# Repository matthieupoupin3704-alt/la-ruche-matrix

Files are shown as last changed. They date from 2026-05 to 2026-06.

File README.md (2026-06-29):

# La Ruche Matrix

**Wi-Fi controlled LED matrix panel for live events: ESP32-S3 + 1 024 WS2812B LEDs on a motorized 2-axis structure.**

Built by Matthieu POUPIN & Marceau GUIGUI - Option Culture Maker, Eirlab / ENSEIRB-MATMECA, 2026.

<p align="center">
  La Ruche Matrix in action
</p>

---

## Overview

La Ruche Matrix is an interactive LED panel designed for music events. The audience connects from their phone and can display scrolling text, draw pixel by pixel, or pick from 31 animations: all in real time, without any app.

- **1 024 RGB LEDs:** 4 × WS2812B 16×16 panels chained together
- **Wi-Fi control:** connect to the panel like a hotspot, open a browser, done
- **31 animations:** Matrix rain, Pac-Man, Game of Life, Pong, 3D cube, audio visualizer...
- **2-axis motorized structure:** repositions the panel without dismounting anything
- **Budget: ~150–160 €**

---

## Demo

<p align="center">
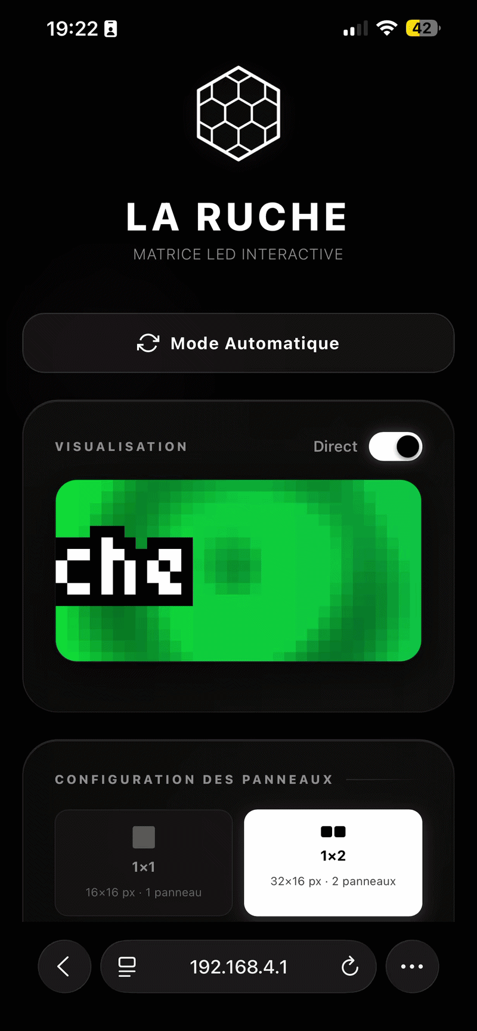
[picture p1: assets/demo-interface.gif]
Web interface demo
  
</p>

---

## Hardware

### Electronics

| Component | Qty | Notes |
|---|-----|---|
| ESP32-S3-N16R8 | 1 | Main controller: Wi-Fi, native USB, 16 MB flash |
| WS2812B 16×16 LED panels | 4 | Individually addressable, chained in series |
| Megatronics v3.3 | 1 | Salvaged, runs Marlin, controls motors via ATmega2560 |
| 19.5 V PSU (modified PC adapter) | 1 | Salvaged |
| XL1509 buck converter | 1 | 19.5 V → 5 V, powers ESP32 |
| BSS138 4-channel level shifter | 1 | 3.3 V ↔ 5 V between ESP32 and Megatronics |
| MAX9814 microphone | 1 | Audio-reactive animations |
| Wires, connectors, perfboard | | |

<p align="center">
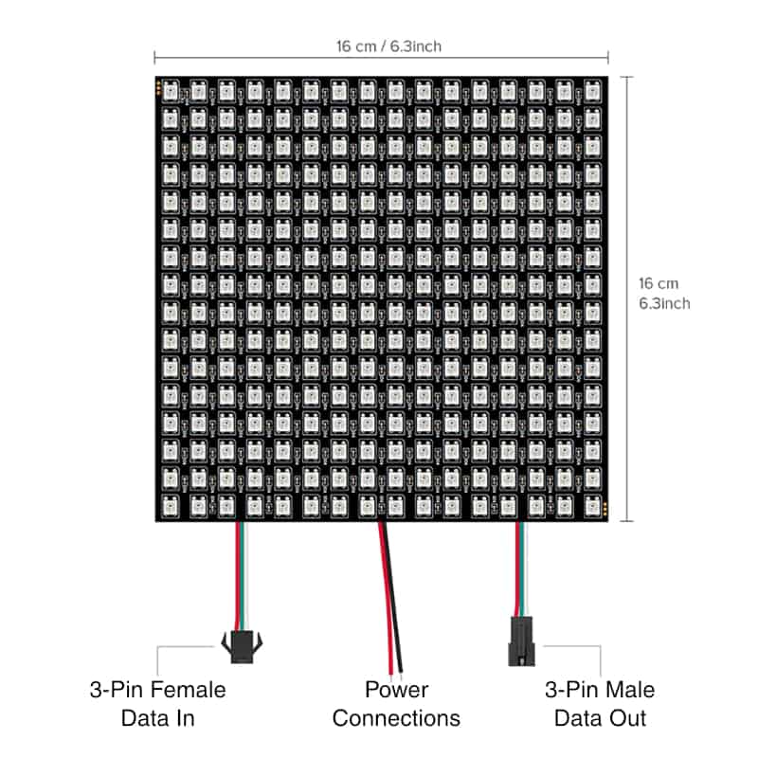
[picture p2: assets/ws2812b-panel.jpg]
WS2812B 16×16 panel and connectors
  
  <br><em>WS2812B 16×16 panel: Data In, Power, Data Out</em>
</p>

<p align="center">
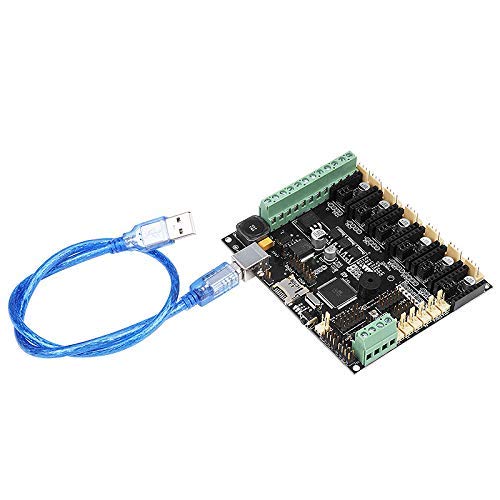
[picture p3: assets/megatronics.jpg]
Megatronics v3.3
  
  <br><em>Megatronics v3.3: runs Marlin, controls the stepper motors</em>
</p>

<p align="center">
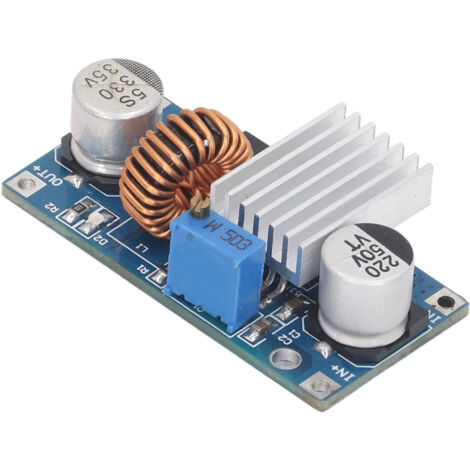
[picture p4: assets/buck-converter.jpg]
XL1509 buck converter
  
  <br><em>XL1509 adjustable buck converter: 19.5 V → 5 V</em>
</p>

### Mechanical

The structure is inspired by a Cartesian 3D printer: two independent axes let you reposition the panel in space without unmounting it from the light bridge.

| Component | Qty | Unit price |
|---|-----|---|
| SH16/SK16 shaft supports | 4 | 6.11 € |
| SH8/SK8 shaft supports | 4 | 4.26 € |
| SC16UU linear bearings (∅16 mm) | 4 | 15.27 € |
| SC8UU linear bearings (∅8 mm) | 2 | 4.95 € |
| ∅16 mm h6 precision shaft (500 mm) | 2 | 9.64 € |
| ∅8 mm h6 precision shaft (500 mm) | 2 | 5.91 € |
| TR10×4P2 trapezoidal leadscrew (500 mm) | 2 | 5.85 € |
| TR10×4P2 bronze/alu leadscrew nut | 2 | 31.63 € |
| D20L25 flexible coupling (5/10 mm) | 2 | 6.60 € |
| GT2 open belt 6 mm (~1 000 mm) | 4 | 7.15 € |
| GT2 20-tooth pulley (5 mm bore) | 2 | 2.27 € |
| NEMA 17 stepper motors (42SH0034D) | 2 | Salvaged (~10 € each otherwise) |
| PLA printed parts | | STL files in this repo |
| Aluminium profiles + hardware | | Frame reinforcement |

**Y axis (vertical):** a NEMA 17 drives a TR10×4P2 trapezoidal leadscrew. A second screw synchronized by belt ensures parallel motion. The bronze nut integral to the carriage moves up or down as the screw turns: slow, precise, and self-locking (no power needed to hold position).

**X axis (horizontal):** the second motor drives a carriage along 16 mm precision shafts via GT2 belt.

<p align="center">
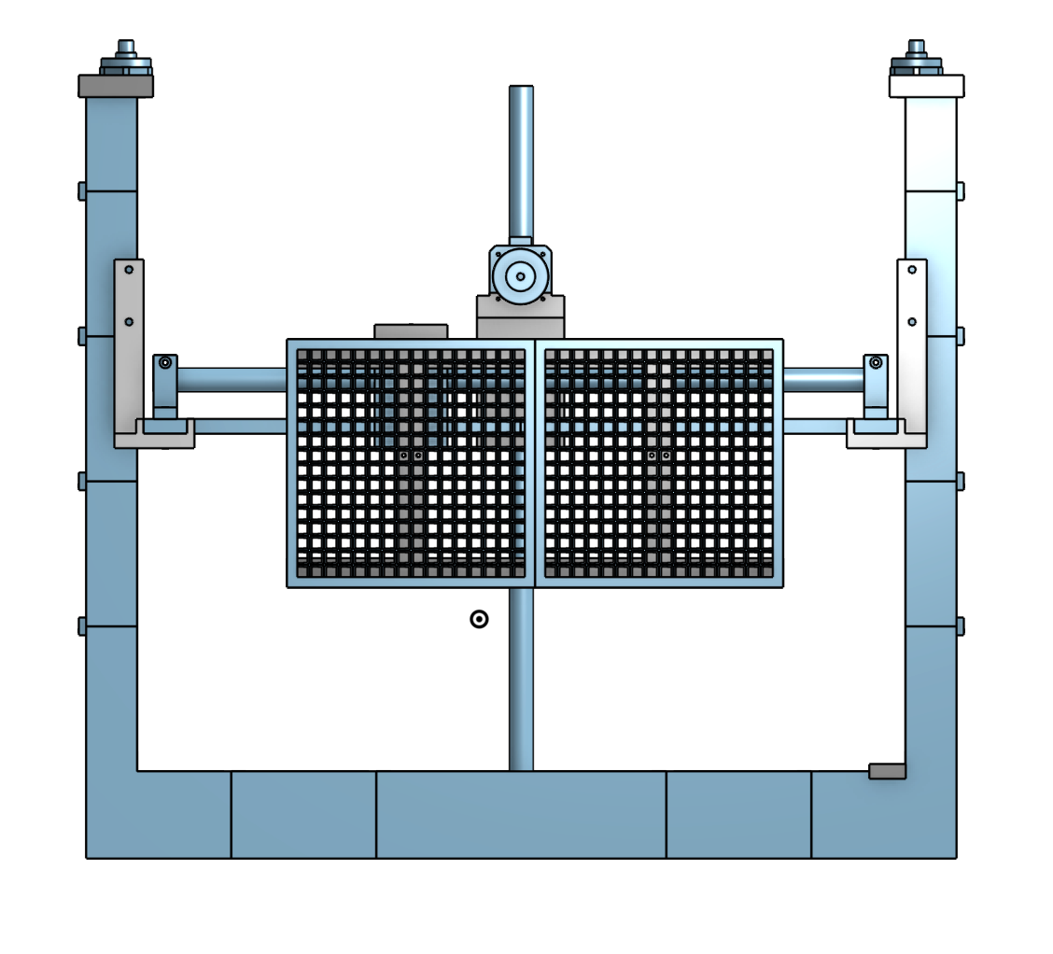
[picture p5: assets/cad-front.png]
CAD front view
  
  <br><em>Front view: 3D CAD of the mechanical structure</em>
</p>

<p align="center">
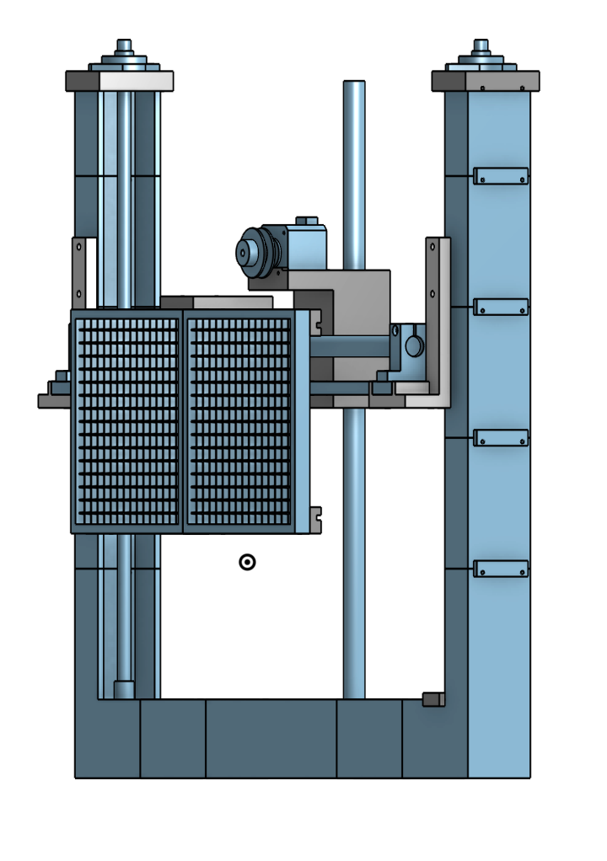
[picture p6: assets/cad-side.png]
CAD side view
  
  <br><em>Side view</em>
</p>

### Tools required

- 3D printer (PLA)
- Soldering iron
- Multimeter
- VSCode + PlatformIO extension

---

## Wiring

19.5 V feeds the XL1509 buck converter, which steps down to 5 V. This 5 V goes into the ESP32-S3's `5V IN` pin; the ESP regulates internally to 3.3 V. The four WS2812B panels are powered from this 3.3 V rail. They tolerate it in practice, and FastLED caps total current at 500 mA. The motors are powered directly at 19.5 V through the Megatronics.

The four panels are chained in series: a single data wire from **GPIO 5** runs through each panel in order. **A common ground between the ESP, panels, and Megatronics is mandatory**. Without it, the data signal is interpreted randomly.

<p align="center">
  Wiring diagram
  <br><em>Simplified wiring diagram</em>
</p>

The ESP32-S3 runs at 3.3 V and the ATmega2560 at 5 V. A BSS138 4-channel level shifter is required between the two.

<p align="center">
  Level shifter wiring
</p>

---

## Firmware

### Quickstart (5 minutes)

1. Install [VSCode](https://code.visualstudio.com/) + the **PlatformIO** extension
2. Clone the repo: `git clone https://github.com/matthieupoupin3704-alt/la-ruche-matrix`
3. Open the folder in VSCode
4. Plug in the ESP32-S3 via USB-C (N16R8 recommended for RAM)
5. In PlatformIO: click **Upload** (`esp32dev` environment)

PlatformIO downloads dependencies, compiles, and flashes automatically.

### Code structure

| File | Role |
|---|---|
| `src/main.cpp` | Web server, scrolling text, settings persistence, dual-core task management |
| `include/effects.h` | 31 animations, each effect is an independent function |

### Dual-core architecture

The ESP32 has two cores: Wi-Fi handles HTTP requests on core 0, while LEDs compute and render on core 1. A mutex protects shared buffers (without it, random visual corruption occurs).

<p align="center">
  Dual-core diagram
  <br><em>Dual-core task architecture</em>
</p>

### Image pipeline

<p align="center">
  Image pipeline
  <br><em>Effect → Topology mapping → Physical output</em>
</p>

### Topologies

Switchable at runtime from the web interface, no recompilation needed. Resolution (`matW`, `matH`) and active LED count are global variables recalculated on the fly. Choice is persisted in ESP flash.

| Topology | Resolution | Panels |
|---|---|---|
| 1×1 | 16×16 px | 1 |
| 1×2 | 32×16 px | 2 side by side |
| 1×4 | 64×16 px | 4 in a strip |
| 2×2 | 32×32 px | 4 in a square |

### Motor control

The Megatronics v3.3 runs Marlin on its ATmega2560. The ESP32 sends G-code over UART (Serial3, 115200 baud). Marlin handles acceleration and motion profiles natively.

```cpp
// Relative mode: no need to track absolute position
snprintf(buf, sizeof(buf), "G91\nG1 Z%.1f X%.1f F%d\nG90", dz, dx, feedrate);
Serial1.println(buf);
```

Emergency stop sends `M410` immediately.

In `marlin_config/Configuration.h`:

```cpp
#define SERIAL_PORT 0      // ATmega native USB
#define SERIAL_PORT_2 3    // Serial3 → ESP32
#define BAUDRATE_2 115200
```

> **Note:** The vertical motor is wired to the Z slot on the Megatronics, not Y. The Y driver was faulty on this salvaged board.

---

## Usage

### Connecting

1. Power on the panel
2. On your phone: Wi-Fi → connect to **La-Ruche-Matrix**
3. Open a browser and go to `192.168.4.1`

The interface works on any mobile browser.

### What you can do

- **Scrolling text:** type a message, pick one of 7 fonts (from tiny pixel art to large sans-serif), send. Text color adapts to the chosen hue.
- **Freehand drawing:** touchscreen canvas for pixel-by-pixel drawing, with pencil, eraser, and a La Ruche logo button.
- **31 animations:** Matrix rain, Doom corridor, Pac-Man, Game of Life, Pong, rotating 3D cube, audio visualizer, and more. Each reacts to hue, speed, and brightness. Some react to sound via the MAX9814 microphone.
- **Panel movement:** touchscreen D-pad sends movement commands, with an emergency stop button.
- **Auto mode:** the panel cycles through animations and fonts every 15 seconds automatically.
- **Live preview:** toggle a real-time view of what's displayed on the panel in your browser, useful for technicians standing behind it.

---

## Adding your own animations

In `include/effects.h`, all animations follow the same pattern:

```cpp
void myEffect() {
    for (uint8_t y = 0; y < MATRIX_H; y++)
        for (uint8_t x = 0; x < MATRIX_W; x++)
            _px(x, y) = CHSV(COULEUR_HUE + x * 4, 255, 200);
}
```

- `_px(x, y)` writes a pixel in logical coordinates
- `COULEUR_HUE` is the hue chosen by the user
- `MATRIX_W` / `MATRIX_H` adapt automatically to the active topology

Then add the function to `_table[]`, its name to `_names[]`, and increment `COUNT`: the interface picks it up automatically.

---

## Known limitations

- **Y axis:** mechanical roughness on one of the vertical shafts now blocks movement
- **X axis:** GT2 belt was particularly difficult to set up (a leadscrew would have been a better choice here)

---

## Acknowledgements

Thanks to [Eirlab](https://www.eirlab.net/) for providing the workspace, equipment loans, and material purchases that made this project possible.

Special thanks to **Julien Allali**, **Antonio Berejano**, and **Adrien Boussicault** for their guidance and support throughout the project.

---

## License

Open source. Code and CAD files available in this repository.

---

*Matthieu POUPIN & Marceau GUIGUI - ENSEIRB-MATMECA, Eirlab, 2026*  
*Full build log: [eirlab.net](https://www.eirlab.net/2026/04/20/lumiere-scenique/)*

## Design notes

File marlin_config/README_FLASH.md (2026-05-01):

# Flasher Marlin sur la Megatronics v3.3

## Prérequis

- Arduino IDE 2.x **ou** PlatformIO
- Câble USB-B (le gros carré, comme pour une imprimante)
- Jumper RESET-EN en place sur la Megatronics (sinon le flash ne fonctionne pas)

## Étapes

### 1. Télécharger Marlin

```bash
git clone https://github.com/MarlinFirmware/Marlin.git
cd Marlin
git checkout release-2.1.2.2
```

### 2. Copier les fichiers de config

Copier `Configuration.h` et `Configuration_adv.h` de ce dossier dans `Marlin/Marlin/`.

```bash
cp /chemin/vers/marlin_config/Configuration.h Marlin/Marlin/
cp /chemin/vers/marlin_config/Configuration_adv.h Marlin/Marlin/
```

### 3. Flash via Arduino IDE

1. Ouvrir `Marlin/Marlin.ino` dans Arduino IDE
2. **Tools → Board** : `Arduino Mega or Mega 2560`
3. **Tools → Processor** : `ATmega2560`
4. **Tools → Port** : le port série de la Megatronics (ex. `/dev/cu.usbserial-XXXX`)
5. Cliquer **Upload**

### 4. Flash via PlatformIO

```bash
cd Marlin
# Vérifier que platformio.ini cible mega2560
pio run -e mega2560 --target upload
```

## Configuration appliquée

| Paramètre | Valeur | Raison |
|---|---|---|
| `SERIAL_PORT` | 3 | Serial3 = connecteur NXT (D14/D15) → ESP32 |
| `BAUDRATE` | 115200 | Vitesse UART ESP32 ↔ ATmega |
| `EXTRUDERS` | 0 | Pas d'extrudeur |
| `TEMP_SENSOR_0` | 0 | Pas de thermisteur |
| `TEMP_SENSOR_BED` | 0 | Pas de plateau chauffant |
| `X_BED_SIZE` | 350 | Course X en mm |
| `Y_BED_SIZE` | 440 | Course Y en mm |
| `DEFAULT_AXIS_STEPS_PER_UNIT` | X=5, Y=50 | GT2+20dents→5pas/mm ; TR10x4P2→50pas/mm |
| Endstops | désactivés | Pas d'endstops sur la structure |

## Câblage ESP32 ↔ Megatronics

La communication passe par le connecteur **NXT** de la Megatronics :

```
Megatronics NXT         Pont logique 3.3V↔5V       ESP32-S3
─────────────────       ─────────────────────       ────────
1. 5V ──────────────── HV (alimentation pont)
2. GND ─────────────── GND ──────────────────────── GND
3. D14 (TX3) ────────── HV1 → LV1 ─────────────────── GPIO44 (RX)
4. D15 (RX3) ────────── LV2 → HV2 ◄──────────────── GPIO43 (TX)
                        LV (3.3V) ◄──── 3.3V ESP32
```

**Important** : ne pas connecter directement 5V ATmega → 3.3V ESP32 sans pont logique.

## Test rapide

Une fois flashé, connecter via le port USB de la Megatronics et envoyer depuis le moniteur série :

```
G28 X Y    ; homing (sans endstops = juste reset position à 0)
G1 X175 Y220 F3000  ; aller au centre
M114       ; afficher la position courante
```

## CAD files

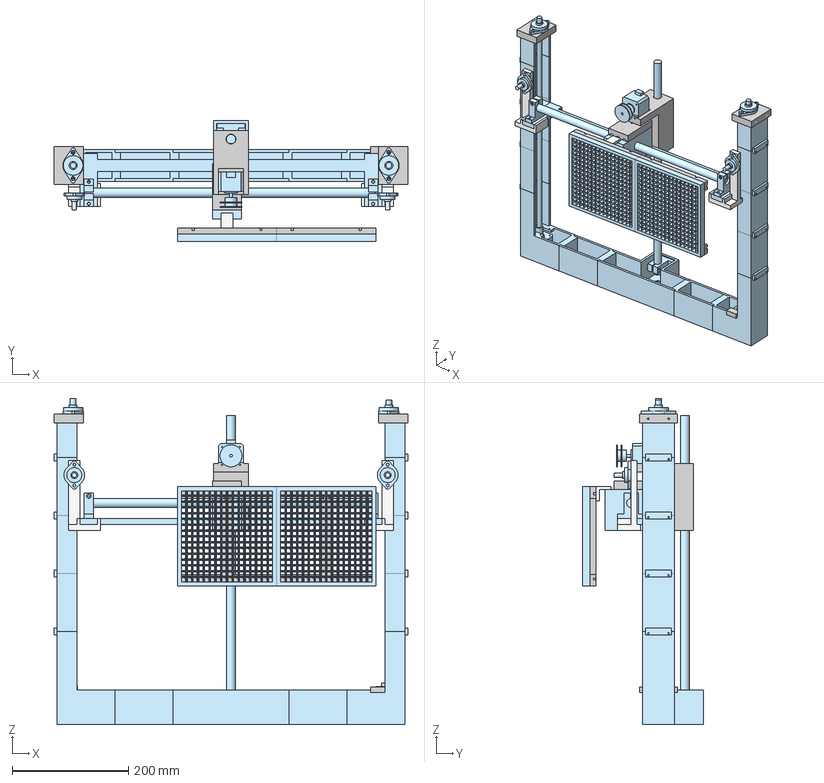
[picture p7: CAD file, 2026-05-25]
Assembly finale.step
610.0 x 208.5 x 562.0 mm

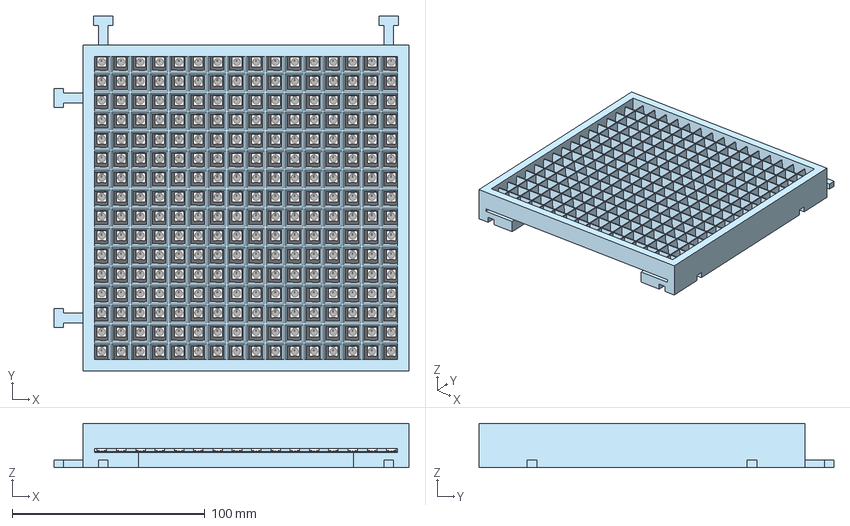
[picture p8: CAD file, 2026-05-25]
Panneau.step
184.0 x 184.0 x 23.0 mm
WS2812_RGB_LED_updated v1 x 256
ws2812b_matrix_16x16 v4

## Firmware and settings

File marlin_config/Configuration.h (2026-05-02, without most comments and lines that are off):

#pragma once
#define CONFIG_EXAMPLES_DIR "config/examples/RepRapWorld/Megatronics"
#define CONFIGURATION_H_VERSION 02010202
#define STRING_CONFIG_H_AUTHOR "La Ruche Matrix" // Who made the changes.
#define SHOW_BOOTSCREEN
  #define MOTHERBOARD BOARD_MEGATRONICS_3
#define SERIAL_PORT 3
#define BAUDRATE 115200
#define X_DRIVER_TYPE  A4988
#define Y_DRIVER_TYPE  A4988
#define Z_DRIVER_TYPE  A4988
#define E0_DRIVER_TYPE A4988
#define EXTRUDERS 0
#define DEFAULT_NOMINAL_FILAMENT_DIA 1.75
#define PSU_CONTROL
  #define PSU_ACTIVE_STATE LOW      // Set 'LOW' for ATX, 'HIGH' for X-Box
#define TEMP_SENSOR_0 0
#define TEMP_SENSOR_1 0
#define TEMP_SENSOR_2 0
#define TEMP_SENSOR_3 0
#define TEMP_SENSOR_4 0
#define TEMP_SENSOR_5 0
#define TEMP_SENSOR_6 0
#define TEMP_SENSOR_7 0
#define TEMP_SENSOR_BED 0
#define TEMP_SENSOR_PROBE 0
#define TEMP_SENSOR_CHAMBER 0
#define TEMP_SENSOR_COOLER 0
#define TEMP_SENSOR_BOARD 0
#define TEMP_SENSOR_REDUNDANT 0
#define DUMMY_THERMISTOR_998_VALUE  25
#define DUMMY_THERMISTOR_999_VALUE 100
#if TEMP_SENSOR_IS_MAX_TC(0)
  #define MAX31865_SENSOR_OHMS_0      100 // (Ω) Typically 100 or 1000 (PT100 or PT1000)
  #define MAX31865_CALIBRATION_OHMS_0 430 // (Ω) Typically 430 for Adafruit PT100; 4300 for Adafruit PT1000
#endif
#if TEMP_SENSOR_IS_MAX_TC(1)
  #define MAX31865_SENSOR_OHMS_1      100
  #define MAX31865_CALIBRATION_OHMS_1 430
#endif
#if TEMP_SENSOR_IS_MAX_TC(2)
  #define MAX31865_SENSOR_OHMS_2      100
  #define MAX31865_CALIBRATION_OHMS_2 430
#endif
#if HAS_E_TEMP_SENSOR
  #define TEMP_RESIDENCY_TIME         10  // (seconds) Time to wait for hotend to "settle" in M109
  #define TEMP_WINDOW                  1  // (°C) Temperature proximity for the "temperature reached" timer
  #define TEMP_HYSTERESIS              3  // (°C) Temperature proximity considered "close enough" to the target
#endif
#if TEMP_SENSOR_BED
  #define TEMP_BED_RESIDENCY_TIME      0  // (seconds) Time to wait for bed to "settle" in M190
  #define TEMP_BED_WINDOW              1  // (°C) Temperature proximity for the "temperature reached" timer
  #define TEMP_BED_HYSTERESIS          3  // (°C) Temperature proximity considered "close enough" to the target
#endif
#if TEMP_SENSOR_CHAMBER
  #define TEMP_CHAMBER_RESIDENCY_TIME 10  // (seconds) Time to wait for chamber to "settle" in M191
  #define TEMP_CHAMBER_WINDOW          1  // (°C) Temperature proximity for the "temperature reached" timer
  #define TEMP_CHAMBER_HYSTERESIS      3  // (°C) Temperature proximity considered "close enough" to the target
#endif
#if TEMP_SENSOR_REDUNDANT
  #define TEMP_SENSOR_REDUNDANT_SOURCE    E1  // The sensor that will provide the redundant reading.
  #define TEMP_SENSOR_REDUNDANT_TARGET    E0  // The sensor that we are providing a redundant reading for.
  #define TEMP_SENSOR_REDUNDANT_MAX_DIFF  10  // (°C) Temperature difference that will trigger a print abort.
#endif
#define HEATER_0_MINTEMP   5
#define HEATER_1_MINTEMP   5
#define HEATER_2_MINTEMP   5
#define HEATER_3_MINTEMP   5
#define HEATER_4_MINTEMP   5
#define HEATER_5_MINTEMP   5
#define HEATER_6_MINTEMP   5
#define HEATER_7_MINTEMP   5
#define BED_MINTEMP        5
#define CHAMBER_MINTEMP    5
#define HEATER_0_MAXTEMP 275
#define HEATER_1_MAXTEMP 275
#define HEATER_2_MAXTEMP 275
#define HEATER_3_MAXTEMP 275
#define HEATER_4_MAXTEMP 275
#define HEATER_5_MAXTEMP 275
#define HEATER_6_MAXTEMP 275
#define HEATER_7_MAXTEMP 275
#define BED_MAXTEMP      150
#define CHAMBER_MAXTEMP  60
#define HOTEND_OVERSHOOT 15   // (°C) Forbid temperatures over MAXTEMP - OVERSHOOT
#define BED_OVERSHOOT    10   // (°C) Forbid temperatures over MAXTEMP - OVERSHOOT
#define COOLER_OVERSHOOT  2   // (°C) Forbid temperatures closer than OVERSHOOT
#define PIDTEMP           // See the PID Tuning Guide at https://reprap.org/wiki/PID_Tuning
#define PID_MAX  255      // Limit hotend current while PID is active (see PID_FUNCTIONAL_RANGE below); 255=full current
#define PID_K1     0.95   // Smoothing factor within any PID loop
    #define DEFAULT_Kp  22.20
    #define DEFAULT_Ki   1.08
    #define DEFAULT_Kd 114.00
#define MAX_BED_POWER 255 // limits duty cycle to bed; 255=full current
#define MAX_CHAMBER_POWER 255 // limits duty cycle to chamber heater; 255=full current
  #define PID_FUNCTIONAL_RANGE 10 // If the temperature difference between the target temperature and the actual temperature
#define PREVENT_COLD_EXTRUSION
#define EXTRUDE_MINTEMP 170
#define PREVENT_LENGTHY_EXTRUDE
#define EXTRUDE_MAXLENGTH 200
#define THERMAL_PROTECTION_HOTENDS // Enable thermal protection for all extruders
#define THERMAL_PROTECTION_BED     // Enable thermal protection for the heated bed
#define THERMAL_PROTECTION_CHAMBER // Enable thermal protection for the heated chamber
#define THERMAL_PROTECTION_COOLER  // Enable thermal protection for the laser cooling
#define USE_ZMIN_PLUG
#define ENDSTOPPULLUPS
#define X_MIN_ENDSTOP_INVERTING true  // Set to true to invert the logic of the endstop.
#define Y_MIN_ENDSTOP_INVERTING true  // Set to true to invert the logic of the endstop.
#define Z_MIN_ENDSTOP_INVERTING true  // Set to true to invert the logic of the endstop.
#define I_MIN_ENDSTOP_INVERTING false // Set to true to invert the logic of the endstop.
#define J_MIN_ENDSTOP_INVERTING false // Set to true to invert the logic of the endstop.
#define K_MIN_ENDSTOP_INVERTING false // Set to true to invert the logic of the endstop.
#define U_MIN_ENDSTOP_INVERTING false // Set to true to invert the logic of the endstop.
#define V_MIN_ENDSTOP_INVERTING false // Set to true to invert the logic of the endstop.
#define W_MIN_ENDSTOP_INVERTING false // Set to true to invert the logic of the endstop.
#define X_MAX_ENDSTOP_INVERTING true  // Set to true to invert the logic of the endstop.
#define Y_MAX_ENDSTOP_INVERTING true  // Set to true to invert the logic of the endstop.
#define Z_MAX_ENDSTOP_INVERTING true  // Set to true to invert the logic of the endstop.
#define I_MAX_ENDSTOP_INVERTING false // Set to true to invert the logic of the endstop.
#define J_MAX_ENDSTOP_INVERTING false // Set to true to invert the logic of the endstop.
#define K_MAX_ENDSTOP_INVERTING false // Set to true to invert the logic of the endstop.
#define U_MAX_ENDSTOP_INVERTING false // Set to true to invert the logic of the endstop.
#define V_MAX_ENDSTOP_INVERTING false // Set to true to invert the logic of the endstop.
#define W_MAX_ENDSTOP_INVERTING false // Set to true to invert the logic of the endstop.
#define Z_MIN_PROBE_ENDSTOP_INVERTING true  // Set to true to invert the logic of the probe.
#define DEFAULT_AXIS_STEPS_PER_UNIT   { 80, 800, 400, 0 }  // 1/16 microstepping DRV8825
#define DEFAULT_MAX_FEEDRATE          { 300, 300, 5, 25 }
#define DEFAULT_MAX_ACCELERATION      { 3000, 3000, 100, 10000 }
#define DEFAULT_ACCELERATION          3000    // X, Y, Z and E acceleration for printing moves
#define DEFAULT_RETRACT_ACCELERATION  3000    // E acceleration for retracts
#define DEFAULT_TRAVEL_ACCELERATION   3000    // X, Y, Z acceleration for travel (non printing) moves
#define DEFAULT_EJERK    5.0  // May be used by Linear Advance
  #define JUNCTION_DEVIATION_MM 0.013 // (mm) Distance from real junction edge
  #define JD_HANDLE_SMALL_SEGMENTS    // Use curvature estimation instead of just the junction angle
#define Z_MIN_PROBE_USES_Z_MIN_ENDSTOP_PIN
#define NOZZLE_TO_PROBE_OFFSET { -25, -29, -12.35 }
#define PROBING_MARGIN 10
#define XY_PROBE_FEEDRATE (133*60)
#define Z_PROBE_FEEDRATE_FAST (4*60)
#define Z_PROBE_FEEDRATE_SLOW (Z_PROBE_FEEDRATE_FAST / 2)
#define Z_CLEARANCE_DEPLOY_PROBE   15 // (mm) Z Clearance for Deploy/Stow
#define Z_CLEARANCE_BETWEEN_PROBES  5 // (mm) Z Clearance between probe points
#define Z_CLEARANCE_MULTI_PROBE     5 // (mm) Z Clearance between multiple probes
#define Z_PROBE_LOW_POINT          -2 // (mm) Farthest distance below the trigger-point to go before stopping
#define Z_PROBE_OFFSET_RANGE_MIN -20
#define Z_PROBE_OFFSET_RANGE_MAX 20
#define X_ENABLE_ON 0
#define Y_ENABLE_ON 0
#define Z_ENABLE_ON 0
#define E_ENABLE_ON 0 // For all extruders
#define DISABLE_OTHER_EXTRUDERS   // Keep only the active extruder enabled
#define INVERT_X_DIR false
#define INVERT_Y_DIR true
#define INVERT_Z_DIR false
#define INVERT_E0_DIR false
#define INVERT_E1_DIR false
#define INVERT_E2_DIR false
#define INVERT_E3_DIR false
#define INVERT_E4_DIR false
#define INVERT_E5_DIR false
#define INVERT_E6_DIR false
#define INVERT_E7_DIR false
#define X_HOME_DIR -1
#define Y_HOME_DIR -1
#define Z_HOME_DIR -1
#define X_BED_SIZE 350
#define Y_BED_SIZE 440
#define X_MIN_POS 0
#define Y_MIN_POS 0
#define Z_MIN_POS 0
#define X_MAX_POS X_BED_SIZE
#define Y_MAX_POS Y_BED_SIZE
#define Z_MAX_POS 200
#define MIN_SOFTWARE_ENDSTOPS
  #define MIN_SOFTWARE_ENDSTOP_X
  #define MIN_SOFTWARE_ENDSTOP_Y
  #define MIN_SOFTWARE_ENDSTOP_Z
  #define MIN_SOFTWARE_ENDSTOP_I
  #define MIN_SOFTWARE_ENDSTOP_J
  #define MIN_SOFTWARE_ENDSTOP_K
  #define MIN_SOFTWARE_ENDSTOP_U
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

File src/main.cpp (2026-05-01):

#include <Arduino.h>
#include <WiFi.h>
#include <WebServer.h>
#include <Preferences.h>
#include <esp_log.h>

#include <Adafruit_GFX.h>
#include <Fonts/FreeMono9pt7b.h>
#include <Fonts/FreeMonoBold12pt7b.h>
#include <Fonts/FreeMonoOblique12pt7b.h>
#include <Fonts/FreeSans9pt7b.h>
#include <Fonts/FreeSans12pt7b.h>
#include <Fonts/FreeSansBold12pt7b.h>
#include <Fonts/FreeSansBold18pt7b.h>
#include <Fonts/FreeSansBoldOblique12pt7b.h>
#include <Fonts/FreeSerif12pt7b.h>
#include <Fonts/FreeSerifItalic12pt7b.h>
#include <Fonts/FreeSerifBoldItalic12pt7b.h>
#include <Fonts/Picopixel.h>
#include <Fonts/TomThumb.h>
#include <Fonts/Org_01.h>

#include "effects.h"
#include <FastLED.h>

// --- config moteurs ---
// ESP32 Serial1 -> pont 3.3V/5V -> Megatronics Serial3 (connecteur NXT). G-code texte.

static constexpr uint8_t  MOTOR_TX    = 43;
static constexpr uint8_t  MOTOR_RX    = 44;
static constexpr uint32_t MOTOR_BAUD  = 115200;
static constexpr float    MOTOR_X_MAX = 350.0f;  // mm, software endstops Marlin
static constexpr float    MOTOR_Y_MAX = 440.0f;

volatile float motorX = 0.0f;
volatile float motorY = 0.0f;

void motorSend(const char* gcode) {
    Serial1.println(gcode);
    Serial.printf("[MOTOR] %s\n", gcode);
}

void motorGoTo(float x, float y, uint16_t feedrate = 3000) {
    x = constrain(x, 0.0f, MOTOR_X_MAX);
    y = constrain(y, 0.0f, MOTOR_Y_MAX);
    motorX = x; motorY = y;
    char buf[48];
    snprintf(buf, sizeof(buf), "G1 X%.1f Y%.1f F%d", x, y, feedrate);
    motorSend(buf);
}

// --- config matrice ---

static constexpr uint8_t  PIN_DATA    = 13;
static constexpr uint8_t  MIC_PIN     = 4;
static constexpr bool     MIC_ENABLED = false;
static constexpr uint8_t  TILE_W      = 16;
static constexpr uint8_t  TILE_H      = 16;
static constexpr uint16_t MAX_LEDS    = TILE_W * TILE_H * 4;  // pire cas : 4 tuiles

static constexpr uint32_t DUREE_EFFET_MS = 15000;
#ifdef WOKWI_SIM
static constexpr uint8_t  TARGET_FPS  = 10;  // simulateur lent
#else
static constexpr uint8_t  TARGET_FPS  = 30;
#endif
static constexpr uint32_t FRAME_DELAY = 1000 / TARGET_FPS;

// --- topologie ---

enum class Topologie : uint8_t { T1x1 = 0, T1x2 = 1, T1x4 = 2, T2x2 = 3 };

uint8_t   matW        = 32;
uint8_t   matH        = 16;
uint16_t  NUM_LEDS    = 32 * 16;
Topologie topoActuelle = Topologie::T1x2;

void applyTopologie(Topologie t) {
    topoActuelle = t;
    switch (t) {
        case Topologie::T1x1: matW = 16; matH = 16; break;
        case Topologie::T1x2: matW = 32; matH = 16; break;
        case Topologie::T1x4: matW = 64; matH = 16; break;
        case Topologie::T2x2: matW = 32; matH = 32; break;
    }
    NUM_LEDS = static_cast<uint16_t>(matW) * matH;
}

// --- réseau & état global ---

WebServer server(80);
String    webSerialBuffer;

// Protège les buffers partagés entre la tâche LED (cœur 1) et le serveur web (cœur 0).
SemaphoreHandle_t matrixMutex;

String  messageGlobal    = "La Ruche";
uint8_t COULEUR_HUE      = 120;
int     vitesseEffets    = 50;
#ifdef WOKWI_SIM
uint8_t luminosite       = 255;
#else
uint8_t luminosite       = 80;
#endif
bool    effetAutomatique = true;
uint8_t effetManuel      = 0;

uint32_t lastFrameTime   = 0;
bool     modeDessin      = false;
volatile bool pendingClearAll = false;

// --- buffers LED ---
// leds[] -> effets -> compositeFrame() -> finalBuffer[] -> flushToDisplay() -> hardwareBuffer[] -> LEDs

CRGB    leds         [MAX_LEDS];
CRGB    finalBuffer  [MAX_LEDS];
CRGB    hardwareBuffer[MAX_LEDS];
uint8_t textMask     [MAX_LEDS];  // 1 = pixel texte/dessin actif

CRGB* pLEDs = leds;

volatile uint8_t audioLevel = 0;

CRGB    cachedTextColor    = CRGB::White;
CRGB    cachedOutlineColor = CRGB::Black;
uint8_t lastHueForText     = 255;

// Texte noir ou blanc selon la luminance de la teinte (pondération BT.601).
void updateTextColors() {
    if (COULEUR_HUE == lastHueForText) return;
    lastHueForText = COULEUR_HUE;
    CRGB base = CHSV(COULEUR_HUE, 240, 200);
    uint32_t luma = static_cast<uint32_t>(base.r) * 299u
                  + static_cast<uint32_t>(base.g) * 587u
                  + static_cast<uint32_t>(base.b) * 114u;
    bool useDark = (luma > 127500u);
    cachedTextColor    = useDark ? CRGB::Black : CRGB::White;
    cachedOutlineColor = useDark ? CRGB::White : CRGB::Black;
}

// --- mapping XY ---
// Coordonnées logiques (x,y) vers index physique. Retourne MAX_LEDS si hors-limites.
// Les panneaux sont cablés en serpentin colonne par colonne (dicte par le fabricant).

#ifdef WOKWI_SIM
uint16_t XY(uint8_t x, uint8_t y) {
    if (x >= MATRIX_W || y >= MATRIX_H) return MAX_LEDS;
    return static_cast<uint16_t>(y) * MATRIX_W + x;
}
#else
uint16_t XY(uint8_t x, uint8_t y) {
    if (x >= MATRIX_W || y >= MATRIX_H) return MAX_LEDS;

    const uint8_t  lx  = x % TILE_W;
    const uint8_t  ly  = y % TILE_H;
    const uint8_t  px  = x / TILE_W;
    const uint8_t  py  = y / TILE_H;
    const uint8_t  tpr = MATRIX_W / TILE_W;
    const uint16_t panelOffset = (static_cast<uint16_t>(py) * tpr + px) * (TILE_W * TILE_H);
    // colonnes impaires inversees : serpentin
    const uint16_t localIdx    = (lx & 1u) ? (lx * TILE_H + (TILE_H - 1u - ly))
                                            : (lx * TILE_H + ly);
    return panelOffset + localIdx;
}
#endif


// --- texte GFX ---

class MatrixTextGFX : public Adafruit_GFX {
public:
    MatrixTextGFX() : Adafruit_GFX(64, 32) {}

    void resize(uint8_t w, uint8_t h) { _width = w; _height = h; }

    void drawPixel(int16_t x, int16_t y, uint16_t color) override {
        if (static_cast<uint16_t>(x) < MATRIX_W && static_cast<uint16_t>(y) < MATRIX_H)
            textMask[static_cast<uint16_t>(y) * MATRIX_W + x] = color ? 1u : 0u;
    }
};

MatrixTextGFX gfxText;

struct FontDef { const char* name; const GFXfont* font; int baselineOffset; };

static const FontDef FONTS[] = {
    {"Standard 5x7",    nullptr,         4},
    {"Micro Pixel",     &Picopixel,     10},
    {"Tom Thumb",       &TomThumb,      10},
    {"Arcade",          &Org_01,        10},
    {"Terminal",        &FreeMono9pt7b, 13},
    {"Clean",           &FreeSans9pt7b, 13},
    {"Gros (Déborde)",  &FreeSans12pt7b,16},
};
static constexpr uint8_t NUM_FONTS = sizeof(FONTS) / sizeof(FONTS[0]);

uint8_t  policeActuelle  = 0;
int16_t  textX           = 32;
int16_t  textWidth       = 0;
uint32_t lastScrollUpdate = 0;
bool     texteEnCours    = false;

void measureText() {
    gfxText.setFont(FONTS[policeActuelle].font);
    int16_t  x1, y1;
    uint16_t w, h;
    gfxText.getTextBounds(messageGlobal, 0, 0, &x1, &y1, &w, &h);
    textWidth = w ? static_cast<int16_t>(w) : static_cast<int16_t>(messageGlobal.length() * 12);
}

uint8_t  effetActuel       = 0;
uint32_t dernierChangement = 0;


// --- serial web ---

void logMessage(const char* msg) {
    Serial.printf("[%lu ms] %s\n", millis(), msg);
    if (webSerialBuffer.length() < 2000)
        webSerialBuffer += "[" + String(millis() / 1000) + "s] " + msg + "<br>";
    else
        webSerialBuffer = webSerialBuffer.substring(1000);
}


// --- page web ---

const char INDEX_HTML[] PROGMEM = R"rawliteral(<!DOCTYPE html>
<html lang="fr">
<head>
  <meta charset="UTF-8">
  <meta name="viewport" content="width=device-width, initial-scale=1.0, maximum-scale=1.0, user-scalable=no, viewport-fit=cover">
  <title>La Ruche Matrix</title>
  <style>
    :root { --bg: #000000; --glass: rgba(20, 20, 20, 0.45); --glass-hover: rgba(35, 35, 35, 0.6); --glass-border: rgba(255, 255, 255, 0.06); --glass-border-light: rgba(255, 255, 255, 0.15); --text: #ffffff; --text-muted: #999999; --r-xl: 32px; --r-lg: 20px; --r-md: 12px; --r-sm: 8px; }
    * { box-sizing: border-box; margin: 0; padding: 0; }
    html { -webkit-text-size-adjust: 100%; scroll-behavior: smooth; }
    body { font-family: -apple-system, BlinkMacSystemFont, "Segoe UI", Helvetica, Arial, sans-serif; background: var(--bg); color: var(--text); min-height: 100dvh; display: flex; flex-direction: column; align-items: center; padding: env(safe-area-inset-top, 40px) 20px calc(env(safe-area-inset-bottom, 0px) + 60px); position: relative; overflow-x: hidden; }
    .bg-blobs { position: fixed; inset: -10%; z-index: 0; pointer-events: none; background: #020202; filter: blur(60px); }
    .blob { position: absolute; border-radius: 50%; background: rgba(255, 255, 255, 0.08); animation: float 20s infinite alternate cubic-bezier(0.45, 0.05, 0.55, 0.95); will-change: transform; }
    .blob-1 { top: 10%; left: 10%; width: 50vw; height: 50vw; background: rgba(255,255,255,0.06); } .blob-2 { top: 40%; right: 10%; width: 60vw; height: 60vw; animation-delay: -5s; animation-direction: alternate-reverse; background: rgba(255,255,255,0.04); } .blob-3 { bottom: 10%; left: 30%; width: 45vw; height: 45vw; animation-delay: -10s; background: rgba(255,255,255,0.05); }
    @keyframes float { 0% { transform: translate(0, 0) scale(1); } 50% { transform: translate(15vw, 10vh) scale(1.1); } 100% { transform: translate(-10vw, 20vh) scale(0.9); } }
    .bg-overlay { position: fixed; inset: 0; z-index: 1; background: rgba(0, 0, 0, 0.5); pointer-events: none; }
    .page { position: relative; z-index: 10; width: 100%; max-width: 500px; display: flex; flex-direction: column; gap: 24px; }
    header { display: flex; flex-direction: column; align-items: center; justify-content: center; margin-bottom: 20px; animation: fadeInDown 0.8s ease-out; }
    @keyframes fadeInDown { from { opacity: 0; transform: translateY(-30px); } to { opacity: 1; transform: translateY(0); } }
    .logo-container { width: 100px; height: 110px; display: flex; align-items: center; justify-content: center; margin-bottom: 16px; animation: pulseLogo 4s ease-in-out infinite alternate; }
    @keyframes pulseLogo { 0% { filter: drop-shadow(0 0 10px rgba(255,255,255,0.1)); transform: scale(1); } 100% { filter: drop-shadow(0 0 25px rgba(255,255,255,0.4)); transform: scale(1.03); } }
    .logo-container svg { width: 100%; height: 100%; }
    .header-info { text-align: center; } .header-info h1 { font-size: 2.2rem; font-weight: 800; letter-spacing: 0.1em; text-transform: uppercase; margin-bottom: 4px; } .header-meta { font-size: 0.85rem; color: var(--text-muted); font-weight: 300; letter-spacing: 0.05em; }
    .card { background: var(--glass); backdrop-filter: blur(40px) saturate(150%); -webkit-backdrop-filter: blur(40px) saturate(150%); border: 1px solid var(--glass-border); border-top: 1px solid rgba(255, 255, 255, 0.15); border-left: 1px solid rgba(255, 255, 255, 0.1); border-radius: var(--r-xl); padding: 28px; box-shadow: 0 30px 60px rgba(0,0,0,0.6), inset 0 1px 0 rgba(255,255,255,0.1); transition: transform 0.3s ease; animation: fadeInUp 0.6s backwards; }
    .card:nth-child(2) { animation-delay: 0.1s; } .card:nth-child(3) { animation-delay: 0.2s; } .card:nth-child(4) { animation-delay: 0.3s; }
    @keyframes fadeInUp { from { opacity: 0; transform: translateY(20px); } to { opacity: 1; transform: translateY(0); } }
    .sec-label { font-size: 0.7rem; font-weight: 800; text-transform: uppercase; letter-spacing: 0.2em; color: var(--text-muted); margin-bottom: 20px; display: flex; align-items: center; gap: 10px; } .sec-label::after { content: ""; flex: 1; height: 1px; background: linear-gradient(90deg, var(--glass-border-light), transparent); }
    .tabs { display: flex; background: rgba(0,0,0,0.4); border-radius: var(--r-md); padding: 6px; margin-bottom: 24px; border: 1px solid var(--glass-border); box-shadow: inset 0 2px 10px rgba(0,0,0,0.5); }
    .tab-btn { flex: 1; text-align: center; padding: 12px; font-weight: 600; font-size: 0.85rem; color: var(--text-muted); cursor: pointer; border-radius: var(--r-sm); transition: 0.3s cubic-bezier(0.4, 0, 0.2, 1); }
    .tab-btn.active { background: var(--text); color: var(--bg); box-shadow: 0 4px 15px rgba(255,255,255,0.2); }
    .pane { display: none; } .pane.active { display: block; animation: fadeIn 0.4s ease-out; } @keyframes fadeIn { from { opacity: 0; } to { opacity: 1; } }
    .msg-row { display: flex; gap: 12px; margin-bottom:12px; } input[type=text] { flex: 1; min-width: 0; background: rgba(0,0,0,0.4); border: 1px solid var(--glass-border); border-radius: var(--r-md); color: var(--text); padding: 16px; font-size: 1rem; outline: none; transition: 0.3s; box-shadow: inset 0 2px 5px rgba(0,0,0,0.5); } input[type=text]:focus { border-color: rgba(255,255,255,0.5); background: rgba(0,0,0,0.6); }
    .btn-action { background: var(--text); color: var(--bg); font-weight: 800; border: none; border-radius: var(--r-md); padding: 0 24px; cursor: pointer; transition: 0.3s cubic-bezier(0.175, 0.885, 0.32, 1.275); } .btn-action:hover { transform: scale(1.05); box-shadow: 0 0 15px rgba(255,255,255,0.3); }
    .btn-reset { width: 100%; padding: 16px; background: rgba(255,255,255,0.06); border: 1px solid var(--glass-border-light); border-radius: var(--r-lg); color: var(--text); font-size: 0.95rem; font-weight: 700; cursor: pointer; transition: 0.3s; letter-spacing: 0.05em; display: flex; align-items: center; justify-content: center; gap: 10px; } .btn-reset:hover { background: var(--text); color: var(--bg); box-shadow: 0 4px 15px rgba(255,255,255,0.2); }
    .select-font { width: 100%; background: rgba(0,0,0,0.4); border: 1px solid var(--glass-border); border-radius: var(--r-md); color: var(--text); padding: 12px 16px; font-size: 0.9rem; font-weight: 600; outline: none; transition: 0.3s; box-shadow: inset 0 2px 5px rgba(0,0,0,0.5); appearance: none; cursor: pointer; }
    .select-font:focus { border-color: rgba(255,255,255,0.5); }
    .canvas-container { width: 100%; background: #000; border-radius: var(--r-lg); margin-bottom: 16px; overflow: hidden; border: 1px solid var(--glass-border); box-shadow: inset 0 0 40px rgba(0,0,0,0.8), 0 10px 30px rgba(0,0,0,0.5); }
    #liveCanvas, #drawCanvas { width: 100%; height: 100%; image-rendering: pixelated; display: block; }
    #drawCanvas { cursor: crosshair; touch-action: none; }
    .draw-tools { display: flex; gap: 10px; } .tool-btn { flex: 1; background: rgba(255,255,255,0.03); color: var(--text-muted); border: 1px solid var(--glass-border); border-top: 1px solid rgba(255,255,255,0.1); border-radius: var(--r-md); padding: 12px; font-size: 0.85rem; font-weight: 600; cursor: pointer; transition: 0.2s; box-shadow: 0 4px 10px rgba(0,0,0,0.2); } .tool-btn.active { background: var(--text); color: var(--bg); border-color: var(--text); } .tool-btn:hover:not(.active) { color: var(--text); border-color: var(--glass-border-light); background: rgba(255,255,255,0.08); }
    .slider-row { margin-bottom: 30px; } .slider-row:last-child { margin-bottom: 0; } .slider-meta { display: flex; justify-content: space-between; align-items: center; margin-bottom: 16px; } .slider-name { font-size: 0.95rem; font-weight: 600; color: var(--text); display: flex; align-items: center; gap: 8px;} .slider-val { font-family: ui-monospace, "SF Mono", Consolas, "Courier New", monospace; font-size: 0.85rem; font-weight: 700; background: rgba(255,255,255,0.1); padding: 4px 10px; border-radius: var(--r-sm); border: 1px solid rgba(255,255,255,0.05); }
    input[type=range] { -webkit-appearance: none; width: 100%; height: 10px; border-radius: 5px; background: rgba(0,0,0,0.5); outline: none; cursor: pointer; box-shadow: inset 0 2px 5px rgba(0,0,0,0.8), 0 1px 0 rgba(255,255,255,0.1); } input[type=range]::-webkit-slider-thumb { -webkit-appearance: none; width: 28px; height: 28px; border-radius: 50%; background: radial-gradient(circle at center, #ffffff 25%, rgba(255,255,255,0.6) 35%, rgba(255,255,255,0.15) 100%); backdrop-filter: blur(4px); border: 1px solid rgba(255, 255, 255, 0.7); box-shadow: 0 4px 12px rgba(0,0,0,0.6), inset 0 2px 4px rgba(255,255,255,0.8); cursor: pointer; transition: transform 0.2s cubic-bezier(0.175, 0.885, 0.32, 1.275), box-shadow 0.2s; } input[type=range]::-webkit-slider-thumb:hover { transform: scale(1.15); box-shadow: 0 6px 16px rgba(0,0,0,0.8), inset 0 2px 6px rgba(255,255,255,1); border-color: #ffffff; }
    #hue { background: linear-gradient(to right, hsl(0,90%,60%), hsl(30,90%,60%), hsl(60,90%,60%), hsl(90,90%,60%), hsl(120,90%,60%), hsl(150,90%,60%), hsl(180,90%,60%), hsl(210,90%,60%), hsl(240,90%,60%), hsl(270,90%,60%), hsl(300,90%,60%), hsl(330,90%,60%), hsl(360,90%,60%)); box-shadow: 0 2px 10px rgba(0,0,0,0.5); } .color-presets { display: flex; gap: 8px; justify-content: space-between; margin-bottom: 16px; } .c-btn { width: 32px; height: 32px; border-radius: 50%; cursor: pointer; border: 2px solid rgba(255,255,255,0.2); transition: 0.3s cubic-bezier(0.175, 0.885, 0.32, 1.275); box-shadow: 0 4px 10px rgba(0,0,0,0.3); } .c-btn:hover { transform: scale(1.2); border-color: #fff; box-shadow: 0 6px 15px rgba(0,0,0,0.5); }
    #lum.unlocked { background: linear-gradient(to right, rgba(255,255,255,0.4) 0%, rgba(255,255,255,0.4) 70%, transparent 70%, transparent 100%), repeating-linear-gradient(45deg, rgba(255,255,255,0.1), rgba(255,255,255,0.1) 10px, rgba(0,0,0,0.6) 10px, rgba(0,0,0,0.6) 20px); } .unlock-btn { background: rgba(255,255,255,0.05); border: 1px solid rgba(255,255,255,0.15); color: var(--text-muted); font-size: 0.7rem; font-weight: 700; padding: 4px 10px; border-radius: 12px; cursor: pointer; transition: 0.3s; text-transform: uppercase; letter-spacing: 0.05em; } .unlock-btn:hover { background: rgba(255,255,255,0.15); color: var(--text); border-color: rgba(255,255,255,0.4); }
    .fx-top { display: flex; align-items: center; justify-content: space-between; margin-bottom: 20px; } .toggle-wrap { display: flex; align-items: center; gap: 10px; cursor: pointer; user-select: none; } .toggle-label { font-size: 0.85rem; font-weight: 600; color: var(--text-muted); transition: 0.2s;} .toggle-wrap:hover .toggle-label { color: var(--text); } .ios-pill { width: 48px; height: 26px; border-radius: 13px; position: relative; background: rgba(0,0,0,0.6); border: 1px solid var(--glass-border); transition: 0.3s; box-shadow: inset 0 2px 5px rgba(0,0,0,0.5); } .ios-pill.on { background: #fff; border-color: #fff; box-shadow: 0 0 10px rgba(255,255,255,0.3); } .ios-knob { position: absolute; top: 2px; left: 2px; width: 20px; height: 20px; border-radius: 50%; background: #888; transition: 0.3s cubic-bezier(0.4, 0, 0.2, 1); box-shadow: 0 2px 4px rgba(0,0,0,0.4); } .ios-pill.on .ios-knob { transform: translateX(22px); background: #000; }
    .fx-grid { display: grid; grid-template-columns: repeat(3, 1fr); gap: 10px; } @media(min-width: 420px) { .fx-grid { grid-template-columns: repeat(4, 1fr); } } .eff-btn { background: rgba(255,255,255,0.03); border: 1px solid var(--glass-border); border-radius: var(--r-md); color: var(--text-muted); font-size: 0.75rem; font-weight: 600; padding: 14px 6px; text-align: center; cursor: pointer; transition: 0.2s; } .eff-btn:hover { background: rgba(255,255,255,0.08); color: var(--text); border-color: var(--glass-border-light); } .eff-btn.active { background: var(--text); border-color: var(--text); color: var(--bg); font-weight: 800; box-shadow: 0 4px 15px rgba(255,255,255,0.2); }
    .topo-grid { display: grid; grid-template-columns: repeat(2, 1fr); gap: 10px; }
    .topo-btn { background: rgba(255,255,255,0.03); border: 1px solid var(--glass-border); border-radius: var(--r-md); color: var(--text-muted); font-size: 0.8rem; font-weight: 700; padding: 14px 8px; text-align: center; cursor: pointer; transition: 0.2s; display: flex; flex-direction: column; align-items: center; gap: 8px; }
    .topo-btn:hover { background: rgba(255,255,255,0.08); color: var(--text); border-color: var(--glass-border-light); }
    .topo-btn.active { background: var(--text); border-color: var(--text); color: var(--bg); box-shadow: 0 4px 15px rgba(255,255,255,0.2); }
    .topo-preview { display: inline-flex; flex-direction: column; gap: 2px; }
    .topo-row { display: flex; gap: 2px; align-items: flex-start; }
    .topo-panel { background: currentColor; border-radius: 2px; opacity: 0.6; flex-shrink: 0; }
    .topo-btn.active .topo-panel { opacity: 1; }
    .topo-info { font-size: 0.65rem; opacity: 0.7; font-weight: 400; }
    .modal-overlay { position: fixed; inset: 0; background: rgba(0,0,0,0.7); backdrop-filter: blur(15px); display: flex; align-items: center; justify-content: center; z-index: 100; opacity: 0; pointer-events: none; transition: 0.3s ease; padding: 20px; } .modal-overlay.active { opacity: 1; pointer-events: all; } .modal { background: rgba(15, 15, 15, 0.85); border: 1px solid rgba(255,255,255,0.15); border-top: 1px solid rgba(255,255,255,0.3); border-radius: var(--r-xl); padding: 32px; width: 100%; max-width: 360px; text-align: center; transform: scale(0.9); transition: 0.3s cubic-bezier(0.175, 0.885, 0.32, 1.275); box-shadow: 0 30px 60px rgba(0,0,0,0.8); } .modal-overlay.active .modal { transform: scale(1); } .modal-icon { margin-bottom: 20px; display: flex; justify-content: center; } .modal-icon svg { width: 48px; height: 48px; color: #fff; filter: drop-shadow(0 0 10px rgba(255,255,255,0.3)); } .modal h3 { font-size: 1.3rem; margin-bottom: 12px; font-weight: 800; text-transform: uppercase; letter-spacing: 0.05em; } .modal p { font-size: 0.9rem; color: var(--text-muted); line-height: 1.6; margin-bottom: 28px; } .modal-actions { display: flex; gap: 12px; } .btn-modal { flex: 1; padding: 14px; border-radius: var(--r-md); font-weight: 700; cursor: pointer; border: none; transition: 0.2s; } .btn-cancel { background: rgba(255,255,255,0.08); color: #fff; border: 1px solid rgba(255,255,255,0.1); } .btn-cancel:hover { background: rgba(255,255,255,0.15); } .btn-confirm { background: #fff; color: #000; } .btn-confirm:hover { transform: scale(1.05); box-shadow: 0 0 20px rgba(255,255,255,0.4); }
    .footer { text-align: center; margin-top: 20px; font-size: 0.75rem; color: rgba(255,255,255,0.4); letter-spacing: 0.05em; line-height: 1.6; } .footer strong { color: rgba(255,255,255,0.8); font-weight: 600; }
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
void loop() { vTaskDelay(pdMS_TO_TICKS(1000)); }

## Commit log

2026-05-01 feat: initial commit — La Ruche Matrix
    Panneau LED matriciel 32×32 px (4× WS2812B 16×16) piloté par un ESP32-S3.
    Interface web Wi-Fi embarquée : 32 animations, texte défilant, dessin pixel,
    contrôle moteurs NEMA 17 via Megatronics v3.3.
2026-05-01 feat: ajout microphone MAX4466 (gain -40 dB) — schéma et article
2026-05-01 fix: microphone MAX4466 → MAX9814 (5 pins : VDD, GND, OUT, Gain, AR)
2026-05-01 chore: retire les README PlatformIO du suivi git
2026-05-01 fix: logo La Ruche en bitmap fixe pré-rasterisé (SVG → pixels exacts par topo)
    [main.cpp]
2026-05-01 feat: config Marlin pour Megatronics v3.3 — 2 axes XY, pas d'endstops, Serial3→ESP32
    [Configuration.h, Configuration_adv.h]
2026-05-01 fix: désactive VALIDATE_HOMING_ENDSTOPS (pas d'endstops physiques)
    [Configuration.h]
2026-05-01 feat(motor): contrôle moteur ATmega/Marlin via Serial1
    - Serial1.begin() sur GPIO43/44 + G92 X0 Y0 à l'init
    - Route HTTP /motor avec commandes goto, stop, reset, positions, programmes
    - Carte UI moteur : sliders X/Y, grille de programmes, arrêt d'urgence
    [main.cpp]
2026-05-01 fix(marlin): remplace le faux Configuration_adv.h (404) par le vrai fichier Megatronics
    [Configuration_adv.h]
2026-05-01 refactor: allege les commentaires dans main.cpp et effects.h
2026-05-01 Ajout de code moteur pour l'ATmega de la megatronics
2026-05-02 fix(marlin): steps/mm x16 pour microstepping 1/16 DRV8825 (X=80, Y=800)
    [Configuration.h]

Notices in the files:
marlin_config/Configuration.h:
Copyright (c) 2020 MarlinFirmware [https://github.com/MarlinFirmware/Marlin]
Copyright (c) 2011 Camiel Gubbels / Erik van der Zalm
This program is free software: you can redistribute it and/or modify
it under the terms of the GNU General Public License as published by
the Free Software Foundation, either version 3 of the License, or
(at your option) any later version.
